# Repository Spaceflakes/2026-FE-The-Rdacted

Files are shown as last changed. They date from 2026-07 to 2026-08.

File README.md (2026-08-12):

# WRO-2026

# The Redacted


**The official repository of The Redacted for WRO - Future Engineers 2026**

## Content

### Folders
- **Engineering Manual:** Official manual of team The Redacted for WRO FE 26 (manual.pdf). Contains component selection, CAD, PCB schematics, and assembly guides.
- **PCBA:** Complete set of KiCad PCB files, manufacturing outputs (Gerbers), interactive HTML BOM, and documentation.
- **t-photos:** Team photos (1 formal, 2 informal).
- **v-photos:** 6 photos of the vehicle (front, back, left, right, top, bottom).
- **video:** video.md file with the official vehicle demonstration video link.
- **schemes:** Schematic diagrams, motor connections, power distribution, and 3D PCB renders.
- **src:** ROS 2 control software nodes (motion, LiDAR, camera/vision, parking logic).
- **models:** 3D CAD model files (STEP format).

### Index
- [The Redacted](#the-redacted)
- [Vehicle Photos and Video](#vehicle-photos-and-video)
- [Hardware Materials](#hardware-materials)
- [Mobility Management](#mobility-management)
- [Design](#design)
- [Power Management and Sense Management](#power-management-and-sense-management)
- [Schematic Diagram](#schematic-diagram)
- [Obstacle Management](#obstacle-management)
- [Our Journal](#our-journal)
- [Gantt Chart](#gantt-chart)

---

## The Redacted

### Members
1. **Anvay Jain**  
   Grade 9, The Sanskaar Valley School. Head of this repository. Interested in Space, Science, KSP, and Mathematics.
2. **Siddesh Jain**  
   12th Grader, Billabong High International School. Lead engineer/development head. CAD, hardware, system architecture.
3. **Prayash**  
   Co-engineer and robotics developer. Software integration, testing, and mechanical assembly.

### Team Pictures
#### Formal
Formal Team Photo

#### Informal
Informal Team Photo 1  
Informal Team Photo 2

---

# Vehicle Photos and Video

### Photos
Vehicle photographs showing all 6 sides are available in the [/v-photos](./v-photos) folder.

### Videos
The demonstration video link and operational breakdown are located in [/video/video.md](./video/video.md).

---

## Hardware Materials

| Name | Link |
| :--- | :--- |
| Rpi 4B/5 | [Link](https://www.raspberrypi.com/products/raspberry-pi-5) |
| LiDAR | [Link](https://robu.in/product/ydlidar-x4-pro-360-degree-ros-scanner-for-navigation-collision-avoidance-10m/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) |
| Servo | [Link](https://robu.in/product/surpass-hobby-25kg-s2500m-servo/) |
| Wheels | [Link](https://robu.in/product/65mm-robot-smart-car-12-rim-wheel-blue/) |
| Pi Camera | [Link](https://robu.in/product/arducam-8mp-imx219-175-degree-ultra-wide-angle-raspberry-pi-camera-module-compatible-with-raspberry-pi-4-model-b-pi-3-3b-and-pi-zero-2w/) |
| Custom 2026 WRO Hat PCB | [Link](https://github.com/The-Redacted/WRO-2026/tree/main/PCBA) |
| ESC + Motor | [Link](https://www.hobbywingdirect.com/collections/quicrun-brushless-system/products/quicrun-wp-10bl120-sl-system-g2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) |
| Battery | 2x DOGCOM 4S 850 mAh 150C LiPo |
| Gears | Custom 3D Printed Bevel Gears |
| PCB Components | TI LM61460 (5.15V @ 6A) & TPS62932 (8V @ 2A) |
| Carbon Fiber Stock | 12mm OD x 10mm ID Tubes & 3mm OD Rods |

### PCB Design & Prototype PCB
#### Prototype PCB
- **Issue:** Standard 5.0V buck converters caused under-voltage warnings on the Pi 4B under load.
- **Solution:** Designed 2026 WRO Hat for a stabilized 5.15V rail at 6A using the TI LM61460.
- **LC Hot-Plug Fix:** Added a 1000 µF electrolytic capacitor between switch output and GND to dissipate inrush energy and prevent voltage ringing.

#### PCB Design
- **4-Layer Stackup:**
    - Layer 1: High-speed switching/control.
    - Layer 2: Ground plane.
    - Layer 3: Power planes (BATT, 5.15V, 8.0V).
    - Layer 4: Ground plane and secondary signals.

---

## Mobility Management
- **Drive System:** Surpass Hobby 3674 1700KV brushless motor + 120A 4S ESC.
- **Differential Gearbox:** 3D-printed, 2:7 gear reduction ratio.
- **Steering:** Direct-drive Ackerman system with S2500M 25 kg-cm servo on 8V rail.
- **Bearing/Axle Support:** Needle roller/thrust bearings for front knuckles; carbon fiber tubes for rear axles.

---

## Design
- **Wheelbase:** 184.3 mm.
- **Width:** <180 mm.
- **Height:** <80 mm.
- **Chassis:** Carbon fiber rods for structural rigidity.

---

## Power Management and Sense Management

### Power Management
- **Battery:** 2x DOGCOM 4S 850 mAh LiPo in parallel (1700 mAh total).
- **5.15V Rail:** TI LM61460 (6A) for RPi 4B and LiDAR.
- **8.0V Rail:** TI TPS62932 (2A) for steering servo.

### Sense Management
- **YD-LiDAR X4 Pro:** 360° 2D Laser Range Finder for mapping/navigation.
- **Arducam IMX219:** 175° FOV camera for pillar color classification.

---

## Schematic Diagram
- **Power Input:** XT30 connector (14.8V–16.8V).
- **Interfaces:** RPi 4B GPIO, USB (LiDAR), CSI (Camera), Expansion Ports (ToF sensors).

---

## Obstacle Management

### Strategy
Uses ROS 2 for modularity, combining LiDAR for 3D mapping and Camera for 2D pillar color classification.

### Logic
- **Round 1 (Open):** Wall-following via LiDAR and lane maintenance.
- **Round 2 (Obstacle):** Pillar detection -> Camera classification -> Dynamic path planning.
- **Parking:** Automated sequence using LiDAR/Camera boundary detection and PID feedback.

---

## Our Journal
- **June:** Strategy, sensing evaluation, concept sketches.
- **July:** CAD modeling, PCB design, tire molding, printing.
- **August:** Assembly, PCB reflow, ROS 2 software development, documentation.

**The journal is one of the most detailed description and accounts for all the decision made. It should most definitely be read.**

---

## Gantt Chart

| Task / Milestone | June | July | August |
| :--- | :--- | :--- | :--- |
| Concept & Selection | X | | |
| 3D CAD Modeling | | X | |
| KiCad PCB Design | | X | |
| SLA Tire Molds | | X | |
| 3D Print & Assembly | | X | X |
| PCB & Reflow | | | X |
| ROS 2 Software | | | X |
| Integration & Testing | | | X |

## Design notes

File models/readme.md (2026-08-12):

# Models Directory (/models) - 3D CAD Files & Hardware Overview

**Team:** The Redacted  
**File Format:** 3D CAD STEP (`.step` / `.stp`)  
**License:** GNU Affero General Public License v3.0 (AGPLv3)

---

## Directory Structure & CAD File Index

This folder contains all 3D CAD models (STEP format), manufacturing jigs/molds, and hardware specifications for the vehicle assembly.

```text
models/
├── Acc/                     # Accessories & Mounting Hardware
│   ├── Raspberry Pi Mount.step  # Mounts RPi 4B to bottom 3mm carbon fiber spine rods (2x M2.5x8mm screws)
│   └── ESC Wire Mount.step      # Zip-tie routing guide for motor and ESC power leads
├── Center/                  # Central Chassis Frame & Sensor Mounts
│   ├── Top Brace.step           # Main structural chassis bridge connecting motor mount to steering column
│   ├── Bottom Left Brace.step   # Interlocking lower left brace connecting top brace to bottom carbon fiber spine
│   ├── Bottom Right Brace.step  # Interlocking lower right brace connecting top brace to bottom carbon fiber spine
│   ├── Left Bearing Mount.step  # Holds BCWG-NK12/12 needle roller bearing and left battery strap
│   ├── Right Bearing Mount.step # Holds BCWG-NK12/12 needle roller bearing and right battery strap
│   └── LiDAR & ESC Mount.step   # Platform mounting YD-LiDAR X4 Pro and Surpass 120A ESC
├── Diff/                    # Differential Gearbox Assembly (2:7 Net Reduction)
│   ├── Spider Gear.step         # 3x 9T Bevel Gears (m=1.5, 20° PA, 30.96° Bevel Angle)
│   ├── Main Gear.step           # 2x 15T Bevel Gears (m=1.5, 20° PA, 59.04° Bevel Angle)
│   ├── Spider Center.step       # Triangular carrier suspending spider gears (via 3x M3x10mm Button Head screws)
│   ├── Left Housing.step        # Left housing half with integrated 28T ring gear (houses 6901ZZ bearing)
│   ├── Right Housing.step       # Right housing half (houses 6901ZZ bearing)
│   ├── Attaching Cup.step       # Split mounting cups connecting main gears to 12mm carbon fiber rear axles
│   └── Spacer Disk.step         # PLA pre-load shim between housing and outer 6901ZZ bearings
├── Rear/                    # Rear Drivetrain & Axle Mounts
│   ├── Rear Axle Mount Front.step # Motor mount housing 3674 motor, bottom carbon rods, and M3 heat-set inserts
│   └── Rear Axle Mount Rear.step  # Rear back mount holding BCWG-NK12/12 & 6901ZZ bearings and top carbon rods
├── Screws BOM.csv           # Complete hardware Bill of Materials (screws, nuts, inserts, standoffs, bearings)
├── Steering/                # Direct-Drive Ackerman Steering Assembly
│   ├── Front Wheel Adapter Pin.step # 12mm OD capped pins with BCWN-T-d12-IR combined needle/thrust bearings
│   ├── Steering Knuckle.step    # Clamping knuckles holding thrust bearings (uses 2x M3x12mm screws & nuts per knuckle)
│   ├── Top Brace.step           # Upper steering column mount for S2500M servo and IMX219 camera
│   ├── Bottom Brace.step        # Lower steering column brace spanning wheelbase
│   ├── Side Brace.step          # Side column braces with M3 heat-set inserts
│   ├── Servo Horn.step          # Clamps to servo shaft with press-fit M3x6mm brass standoff spacer
│   ├── Servo Link.step          # Linkage arm connecting servo horn to steering rod
│   ├── Wheel Link.step          # Linkage arm connecting steering rod to steering knuckle (uses M2x20mm screw)
│   └── TPU Spacer.step          # 95A TPU shims (16mm OD x 12.8mm ID) providing pre-load on thrust bearings
├── Tools/                   # Manufacturing Jigs & Fabrication Molds
│   ├── Tire Mold.step           # 2-part SLA/FDM mold for polyurethane tires (clamps with 4x M3x30mm screws & nuts)
│   ├── Standoff Cutting Tool.step # Razor slot jig for trimming nylon standoffs to 14mm
│   ├── Axle Cutting Jig.step    # Saw guide for cutting 12mm carbon fiber tube axles to ~60mm
│   └── Axle Drilling Guide.step # Precision guide for drilling 2mm holes at 4.5mm offset on carbon fiber tubes
└── Wheel Hub.step           # 3D STEP model for custom wheel hub (18mm width, fuzzy skin tire interface)
```

## 3D Printing & Material Guidelines

* **Slicer Setup:** Orca Slicer / PreFlight using the Arachne wall engine.
* **Perimeters & Infill:** 3 perimeters (0.4 mm nominal nozzle), 25% Gyroid infill. Use 100% solid infill for steering links and TPU spacers.
* **Layer Heights:** 0.20 mm for structural chassis parts and mounts; 0.12 mm for gears, differential housing, and steering linkage parts.
* **Materials:**
  * **PLA:** Standard chassis structures, gears, housing, and mounts.
  * **TPU (95A Shore Hardness):** Front bearing stack pre-load shims (`Steering/TPU Spacer`).
  * **Resin (SLA):** Two-part polyurethane tire casting molds (`Tools/Tire Mold`).
* **Non-Printed Stock:** 12mm OD x 10mm ID roll-wrapped carbon fiber tubes (rear axles) and 3mm OD solid pultruded carbon fiber rods (spine and steering rods).

---

## Hardware Summary (Screws BOM.csv)

A complete component-by-component hardware listing is provided in `Screws BOM.csv` within this folder, including:

* **Screws:** M2x12mm, M2x20mm, M2.5x8mm, M3x8mm (Socket/CSK), M3x10mm (Socket/Button/CSK), M3x12mm, M3x16mm, M3x20mm (Socket/Button), M3x30mm.
* **Nuts & Inserts:** M2, M2.5, M3 Hex Nuts; M3x4mm and M3x6mm Brass Threaded Heat-Set Inserts.
* **Standoffs & Bearings:** M2.5x15mm Nylon Standoffs (cut to 14mm), M3x6mm Brass Standoffs, BCWN-T-d12-IR Thrust Bearings, 6901ZZ Ball Bearings, and BCWG-NK12/12 Needle Roller Bearings.

---

## License

All CAD files (`.STEP`) in this directory are released under the **GNU Affero General Public License v3.0 (AGPLv3)**. Any modified or derivative 3D models must be made publicly available under the same license terms.

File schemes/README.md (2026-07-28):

Electromechanical diagrams
====

`PCB V1.1 Schematic.pdf` is the PDF output of the schematic from KiCAD. It is the electrical schematic of the PCB used. Version 1.0 had an error (covered in `Engineering Manua/manual.pdf`. V1.1 is the fixed version.

The schematic is divided into 3 pages. The main page has the power connector and the power switch. The power page containst he circuitry for the buck converters. The logic page has the Raspberry Pi and the sensor connection.

The ROS2 node schematic will also be added here.

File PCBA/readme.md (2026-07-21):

# PCB Design Files

This directory contains the complete set of KiCad Printed Circuit Board (PCB) files, manufacturing outputs, and documentation required to view, modify, assemble, and produce this board.
---

## Directory Contents

Here is a quick overview of the essential files included in this folder:

| File / Folder Name | Type | Description |
| --- | --- | --- |
| **`interactive bom.html`** | HTML | Interactive Bill of Materials tool for easy manual assembly and component placement. |
| **`PCB BOM.csv`** | CSV | The complete, standard Bill of Materials listing all required electronic components, values, and footprints. |
| **`PCB_Schematic.pdf`** | PDF | A high-resolution PDF export of the circuit schematic for quick reference without needing CAD software. |
| **`KiCAD/production/WRO_Hat_V1.5.zip`** | ZIP Archive | The compiled Gerber and Drill files, ready to be uploaded to your favorite PCB manufacturer. |
| **KiCad Source Files** | KiCad | The raw `.kicad_pro`, `.kicad_sch`, and `.kicad_pcb` files for editing the design. |

---

## Detailed File Breakdown

### 1. The Interactive BOM (`interactive bom.html`)

This is a highly useful tool generated by the **InteractiveHtmlBom** plugin. If you plan on soldering this board yourself, simply open this file in any modern web browser. It provides a visual representation of the PCB, allowing you to highlight components, track your progress, and see exactly where each part belongs.

### 2. Standard Bill of Materials (`PCB BOM.csv`)

If you are ordering parts from suppliers like DigiKey, Mouser, or LCSC, this CSV file is your go-to resource. It contains a tabular breakdown of every resistor, capacitor, IC, and connector required.

### 3. Manufacturing Gerbers (`WRO_Hat_V1.5.zip`)

This ZIP archive contains all the industry-standard RS-274X Gerber files and Excellon drill files required by board houses (such as JLCPCB, PCBWay, or OSH Park).

* **Location:** Navigate to the `KiCAD/production/` folder to find this archive.
* **Usage:** Simply upload the `.zip` file directly to the manufacturer's quote page.

### 4. Schematic Reference (`PCB_Schematic.pdf`)

For software engineers writing firmware or hardware reviewers checking pinouts, the PDF schematic offers a clean, easily readable map of the entire circuit. It is fully searchable, making it easy to trace specific signals or power rails.

---

## Getting Started with KiCad

If you want to view or modify the raw board design:

1. Ensure you have the latest version of **KiCad EDA** installed on your system.
2. Clone or download this repository to your local machine.
3. Open the `.kicad_pro` project file in the main directory.
4. Launch the **Schematic Editor** or **PCB Editor** directly from the KiCad project manager.

---

> Important Note: Before sending the Gerber files for manufacturing, please verify that the design meets your specific board house's capabilities and tolerances (minimum trace width, hole size, and clearance).

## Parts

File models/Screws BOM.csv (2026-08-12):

Category | Component | Specification / Fastener Type | Head / Drive Type | Assembly Qty | Application / Where Needed
Screws | M2 x 12mm Screw | M2 x 12mm | Socket Head | 4 | Wheel Hubs to Axles (1x per wheel hub across 4 wheels)
Screws | M2 x 20mm Screw | M2 x 20mm | Socket Head | 6 | Steering Links to Knuckles (2x) and Front/Rear Axle Pins (4x)
Screws | M2.5 x 8mm Screw | M2.5 x 8mm | Socket Head (Black Oxide) | 6 | Raspberry Pi Mount to Pi (2x) and Pi to Nylon Standoffs (4x)
Screws | M3 x 8mm Screw | M3 x 8mm | Socket Head | 22 | Motor to Front Mount (6x) Rear Axle Back Mount (8x) Top Brace to Motor Mount (6x) Top Brace to Knuckles (2x)
Screws | M3 x 8mm CSK Screw | M3 x 8mm | Countersunk (CSK) | 2 | Bottom Brace to Steering Knuckles (2x)
Screws | M3 x 10mm Screw | M3 x 10mm | Socket Head | 2 | Servo Link to Steering Linkage Pins (2x)
Screws | M3 x 10mm Button Screw | M3 x 10mm | Button Head | 3 | Differential Gearbox Spider Center suspension (3x)
Screws | M3 x 10mm CSK Screw | M3 x 10mm | Countersunk (CSK) | 5 | LiDAR & ESC Mount to LiDAR (3x) and Bottom Brace to Side Braces (2x)
Screws | M3 x 12mm Screw | M3 x 12mm | Socket Head | 6 | Steering Knuckle Clamps (2 per clamp x 2 knuckles = 4x) and Top Brace to Steering Mount (2x)
Screws | M3 x 16mm Screw | M3 x 16mm | Socket Head | 2 | Optional frame structural reinforcement / general assembly
Screws | M3 x 20mm Screw | M3 x 20mm | Socket Head | 4 | Steering Servo to Top Brace (4x)
Screws | M3 x 20mm Button Screw | M3 x 20mm | Button Head | 4 | Differential Main Gears to Axle Attaching Cups (2 per gear x 2 gears = 4x)
Screws | M3 x 30mm Screw | M3 x 30mm | Socket Head | 7 | Differential Gearbox Housing halves (3x) and Tire Mold Tool clamping (4x)
Nuts | M2 Hex Nut | M2 | Hex (SS304) | 4 | Wheel Hub and Axle pin retention nuts
Nuts | M2.5 Hex Nut | M2.5 | Hex (SS304) | 4 | Raspberry Pi Mount and Standoff retention nuts
Nuts | M3 Hex Nut | M3 | Hex (SS304 / Mild Steel) | 11 | Steering Knuckle Clamps (4x) Differential Housing (3x) and Tire Mold Tool clamping (4x)
Standoffs | M2.5 Nylon Standoff | M2.5 x 15mm (cut to 14mm) | Female-Female Hex | 4 | Mounting spacing between Raspberry Pi 4B and Custom PCB Hat
Standoffs | M3 Brass Standoff | M3 x 6mm | Female-Female Hex | 1 | Press-fit spacer inside Servo Horn (1x)
Heat-Set Inserts | M3 x 4mm Heat-Set Insert | M3 x 4mm (3mm OD) | Slant Knurled Brass | 4 | Rear Axle Front Mount (Motor Mount) rear interface to Back Mount (4x)
Heat-Set Inserts | M3 x 6mm Heat-Set Insert | M3 x 6mm (3mm OD) | Slant Knurled Brass | 19 | Top Brace front (2x) Side Braces (6x) Rear Axle Front Mount sides (6x) Top Brace center (2x) LiDAR/ESC Mount (3x)
Bearings | Combined Needle/Thrust Bearing | BCWN-T-d12-IR (12mm ID) | Roller Thrust | 2 | Front Steering Knuckles (2x)
Bearings | Deep Groove Ball Bearing | 6901ZZ (12mm ID x 24mm OD x 6mm W) | Ball Bearing | 4 | Differential Gearbox Internal (2x) and External Housing Mounts (2x)
Bearings | Needle Roller Bearing | BCWG-NK12/12 (12mm ID x 19.5mm OD x 12mm D) | Needle Roller | 2 | Rear Axle Support Mounts (2x)
Carbon Fiber | 12mm Carbon Fiber Tube | 12mm OD x 10mm ID x 500mm | Roll Wrapped Twill | 1 | Rear Wheel Axles (2x cut to ~60mm)
Carbon Fiber | 3mm Carbon Fiber Rod | 3mm OD Solid x 1000mm | Pultruded Toe | 2 | Chassis Structural Spine (4x) and Steering Linkage Rods (2x cut to ~48mm)

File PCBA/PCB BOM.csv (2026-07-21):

Id | Designator | Footprint | Quantity | Designation | Supplier and ref
1 | C1, C2, C3, C4 | C_0603_1608Metric | 4 | 4.7u
2 | C5, C6, C7, C18 | C_0603_1608Metric | 4 | 47u
3 | C8, C9 | C_0603_1608Metric | 2 | 220n
4 | C10 | C_0603_1608Metric | 1 | 1u
5 | C11 | C_0603_1608Metric | 1 | 1p
6 | C12, C14, C16 | C_0603_1608Metric | 3 | 100n
7 | C13 | C_0603_1608Metric | 1 | 10u
8 | C15 | C_0603_1608Metric | 1 | 33n
9 | C17 | C_0603_1608Metric | 1 | 12p
10 | C19 | CP_Elec_8x10 | 1 | 220u
11 | C20 | CP_Elec_10x10 | 1 | 270u
12 | D1 | LED_D5.0mm | 1 | LED
13 | J1 | PinSocket_2x20_P2.54mm_Vertical | 1 | Raspberry_Pi_4
14 | J2 | AMASS_XT30PW-M_1x02_P2.50mm_Horizontal | 1 | XT30_Power
15 | J3 | PinHeader_1x05_P2.54mm_Vertical | 1 | TOF_Right
16 | J4 | PinHeader_1x05_P2.54mm_Vertical | 1 | TOF_Left
17 | L1 | L_Chilisin_BMRF00101040 | 1 | 6.8u
18 | L2 | L_Chilisin_BMRA00040415 | 1 | 15u
19 | M1 | PinHeader_1x03_P2.54mm_Horizontal | 1 | Throttle
20 | M2 | PinHeader_1x03_P2.54mm_Horizontal | 1 | Steering
21 | M3 | PinHeader_1x03_P2.54mm_Horizontal | 1 | Extra
22 | R1 | R_0603_1608Metric | 1 | 32.4k
23 | R2, R5 | R_0603_1608Metric | 2 | 100k
24 | R3 | R_0603_1608Metric | 1 | 1k
25 | R4 | R_0603_1608Metric | 1 | 24.3k
26 | R6 | R_0603_1608Metric | 1 | 90.9k
27 | R7 | R_0603_1608Metric | 1 | 10k
28 | SW1 | Switch | 1 | POWER
29 | SW2 | Switch | 1 | Program
30 | U1 | IC_LM61460AFSQRJRRQ1 | 1 | LM61460AFSQRJRRQ1
31 | U2 | SOT-583-8 | 1 | TPS62932

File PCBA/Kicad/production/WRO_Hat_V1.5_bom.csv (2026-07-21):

Designator | Footprint | Quantity | Value | LCSC Part #
C1, C2, C3, C4 | 0603 | 4 | 4.7u
C10 | 0603 | 1 | 1u
C11 | 0603 | 1 | 1p
C12, C14, C16 | 0603 | 3 | 100n
C13 | 0603 | 1 | 10u
C15 | 0603 | 1 | 33n
C17 | 0603 | 1 | 12p
C18 | 0805 | 1 | 47u
C19 | CP_Elec_8x10 | 1 | 220u | C341198
C20 | CP_Elec_10x10 | 1 | 270u | C251008
C5, C6, C7 | 0603 | 3 | 47u
C8, C9 | 0603 | 2 | 220n
D1, D2 | LED_D5.0mm | 2 | LED
J1 | PinSocket_2x20_P2.54mm_Vertical | 1 | Raspberry_Pi_4
J2 | AMASS_XT30PW-M_1x02_P2.50mm_Horizontal | 1 | XT30_Power
J3 | PinHeader_1x05_P2.54mm_Vertical | 1 | TOF_Right
J4 | PinHeader_1x05_P2.54mm_Vertical | 1 | TOF_Left
L1 | L_Chilisin_BMRF00101040 | 1 | 6.8u
L2 | L_Chilisin_BMRB00060618 | 1 | 15u
M1 | PinHeader_1x03_P2.54mm_Horizontal | 1 | Throttle
M2 | PinHeader_1x03_P2.54mm_Horizontal | 1 | Steering
M3 | PinHeader_1x03_P2.54mm_Horizontal | 1 | Extra
R1 | 0603 | 1 | 32.4k
R2, R5 | 0603 | 2 | 100k
R3 | 0603 | 1 | 1k
R4 | 0603 | 1 | 24.3k
R6 | 0603 | 1 | 90.9k
R7 | 0603 | 1 | 10k
SW1 | Switch | 1 | POWER
SW2 | Switch | 1 | Program
U1 | IC_LM61460AFSQRJRRQ1 | 1 | LM61460AFSQRJRRQ1 | C2871455
U2 | SOT-583-8 | 1 | TPS62932

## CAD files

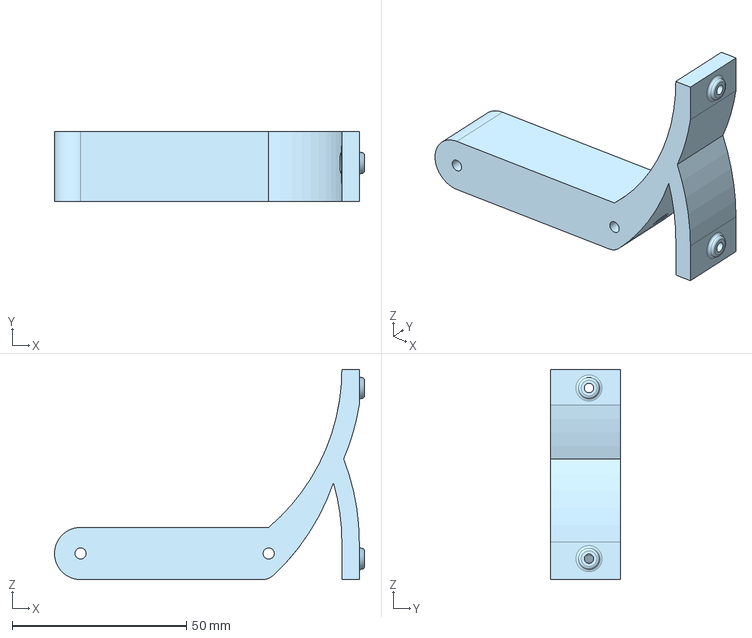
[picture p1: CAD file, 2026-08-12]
models/Acc/PI mount.step
89.0 x 20.0 x 60.4 mm

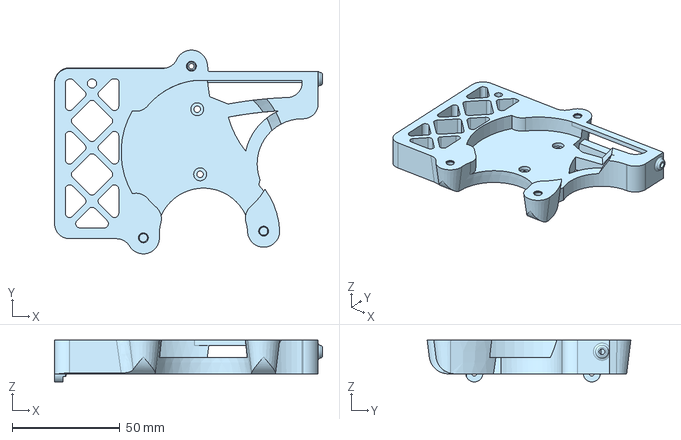
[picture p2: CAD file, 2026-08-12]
models/Center/Lidar Mount.step
124.3 x 94.5 x 19.4 mm

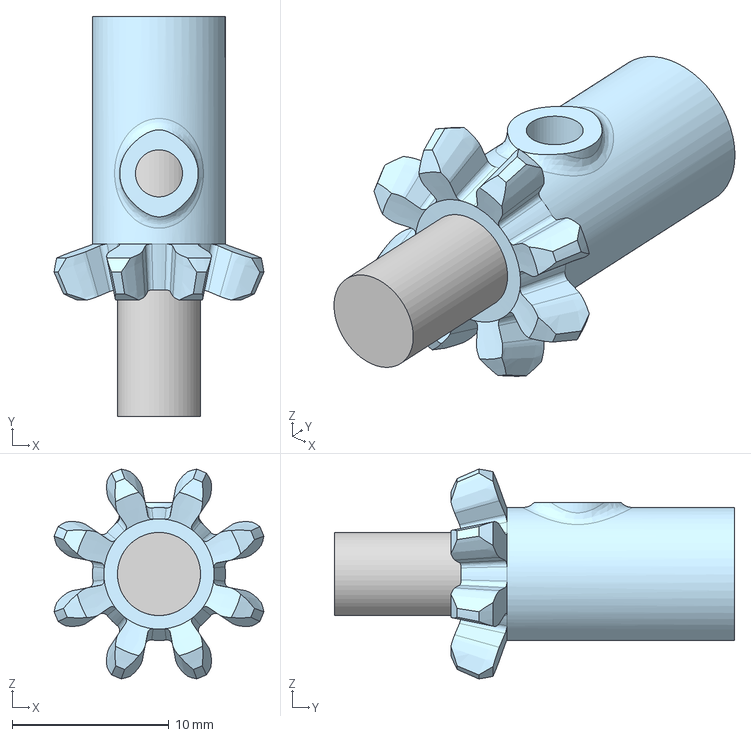
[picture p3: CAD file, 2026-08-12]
models/Diff/Motor Gear.step
13.4 x 25.5 x 13.4 mm

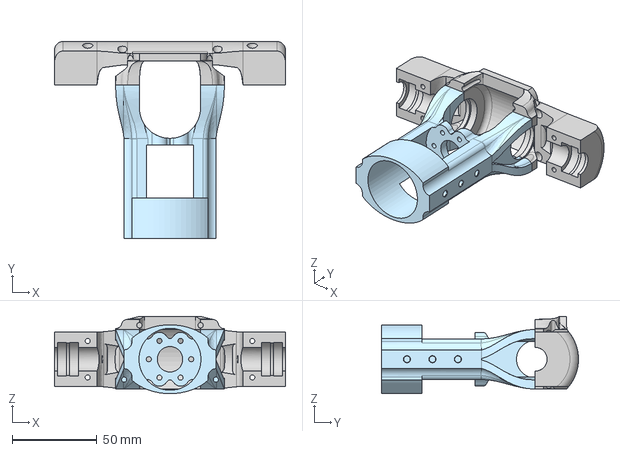
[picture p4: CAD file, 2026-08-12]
models/Rear/Rear Gearbox Mount.step
136.0 x 116.0 x 45.5 mm

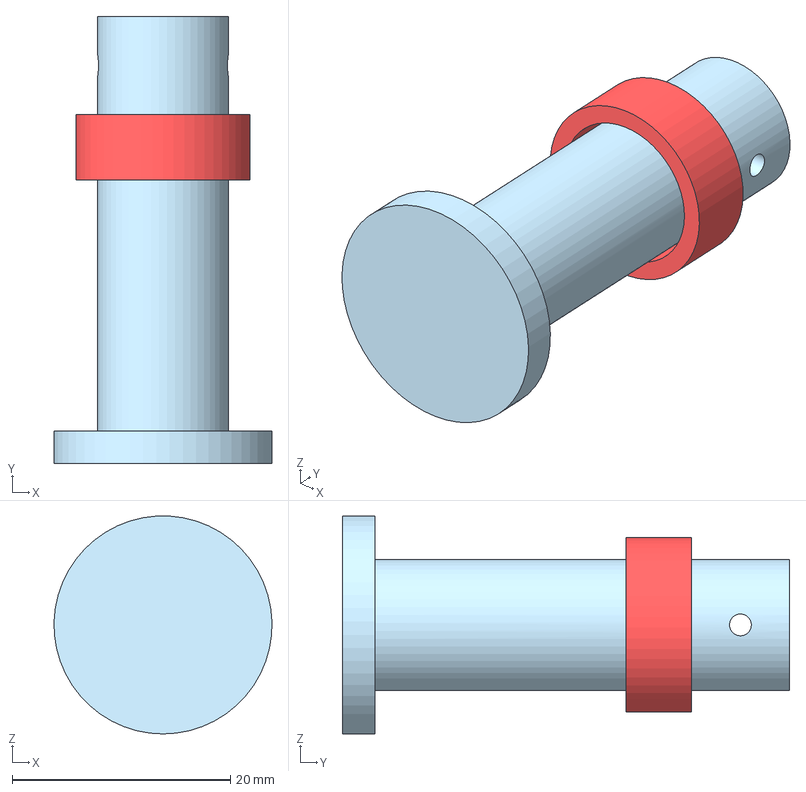
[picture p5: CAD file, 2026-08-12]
models/Steering/Front Wheel adapter.step
20.0 x 41.0 x 20.0 mm

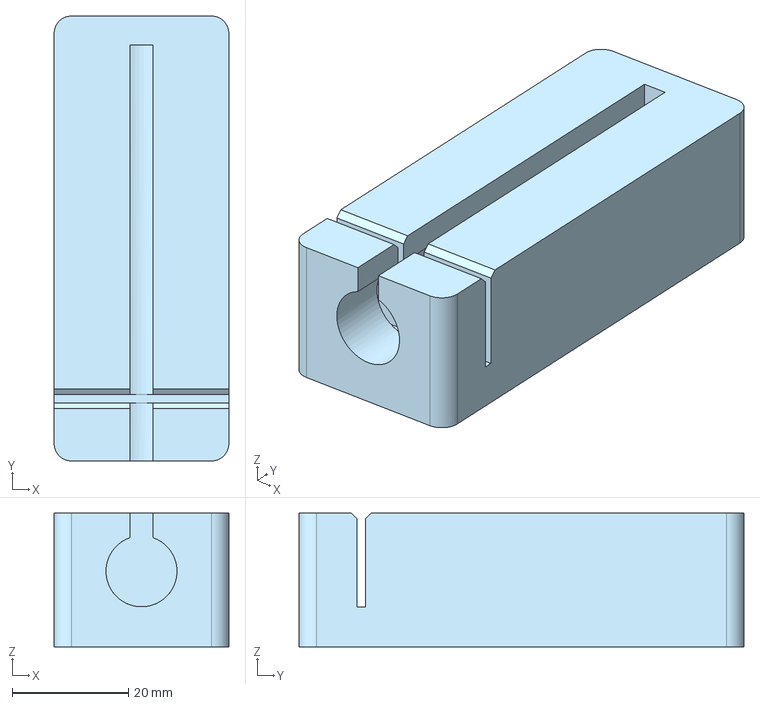
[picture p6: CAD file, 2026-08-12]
models/Tools/Rod Cutting Tool.step
30.0 x 76.4 x 23.0 mm

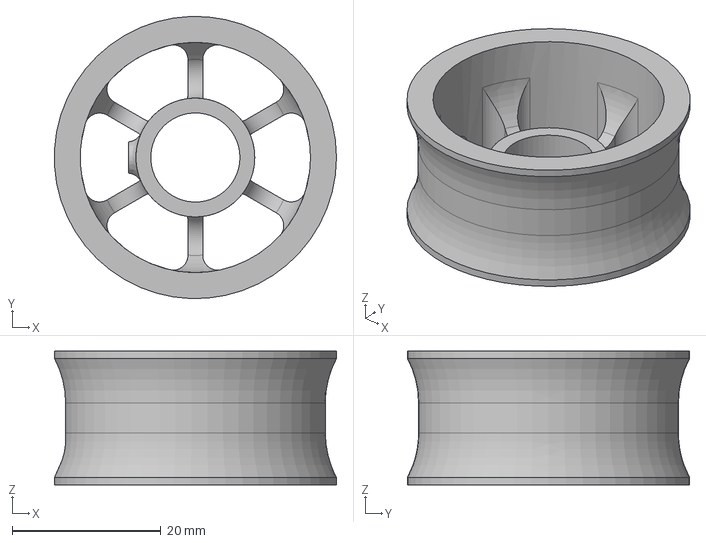
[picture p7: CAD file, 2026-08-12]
models/Wheel Hub.step
38.0 x 38.0 x 18.0 mm

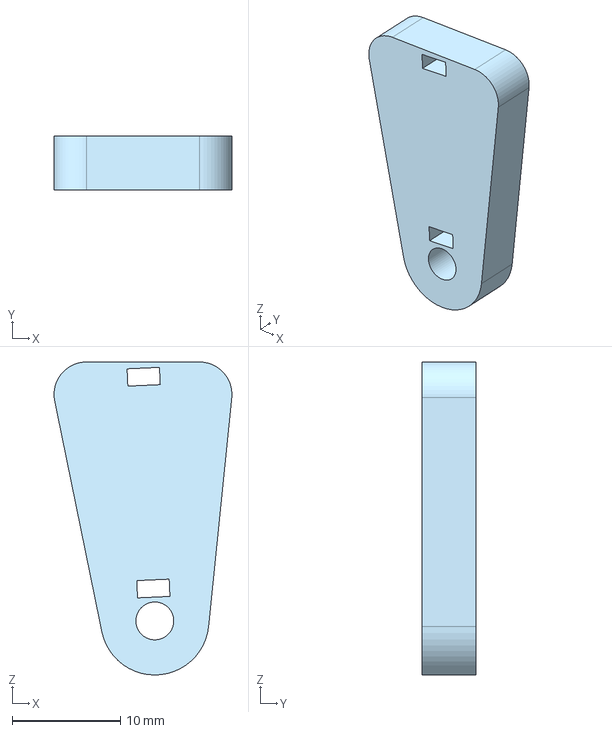
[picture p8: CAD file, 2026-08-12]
models/Acc/ESC Wire mount.step
16.4 x 5.00 x 28.9 mm

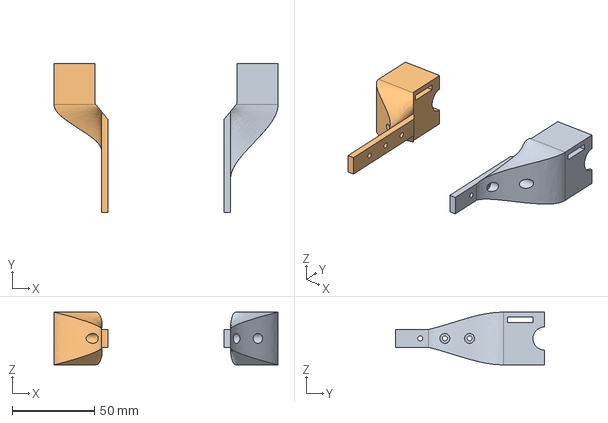
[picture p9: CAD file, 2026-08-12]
models/Center/Rear Bearing Mount.step
136.0 x 90.5 x 32.0 mm

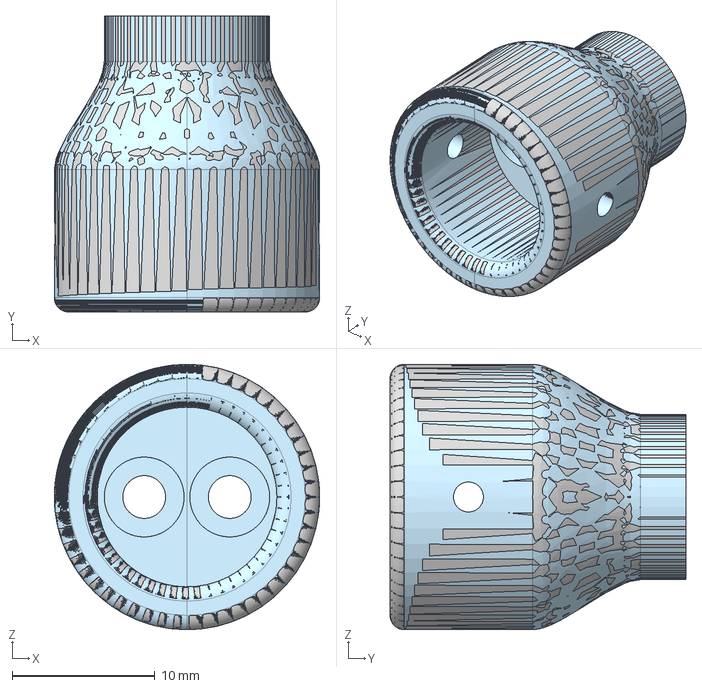
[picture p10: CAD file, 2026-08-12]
models/Diff/Cups.step
18.6 x 20.8 x 18.6 mm

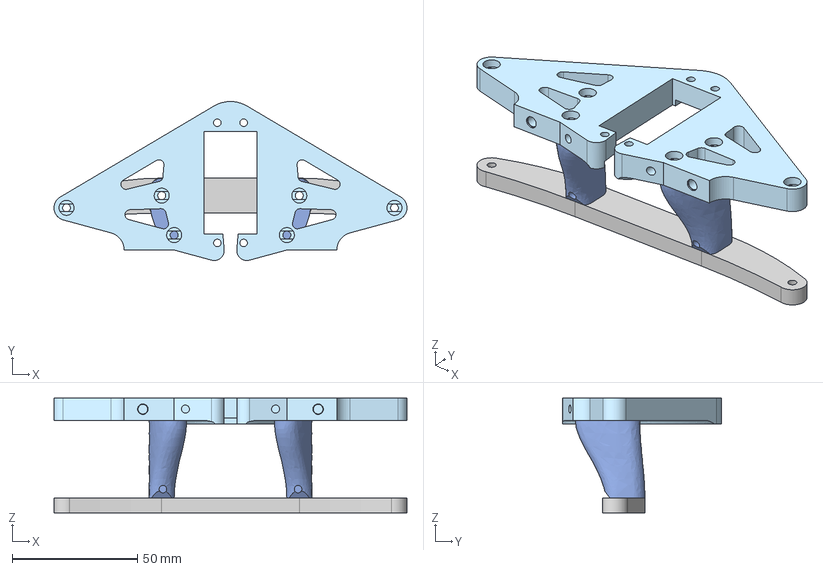
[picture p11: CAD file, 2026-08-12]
models/Steering/Steering COl.step
141.0 x 63.5 x 45.9 mm

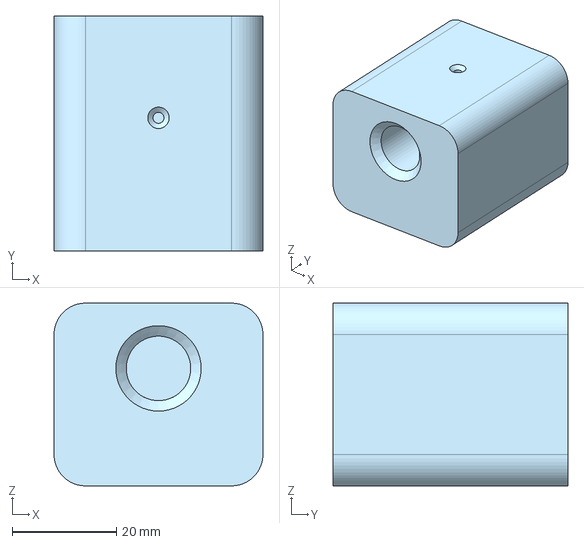
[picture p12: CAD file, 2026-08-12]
models/Tools/Rod Drilling Tool.step
40.0 x 45.0 x 35.0 mm

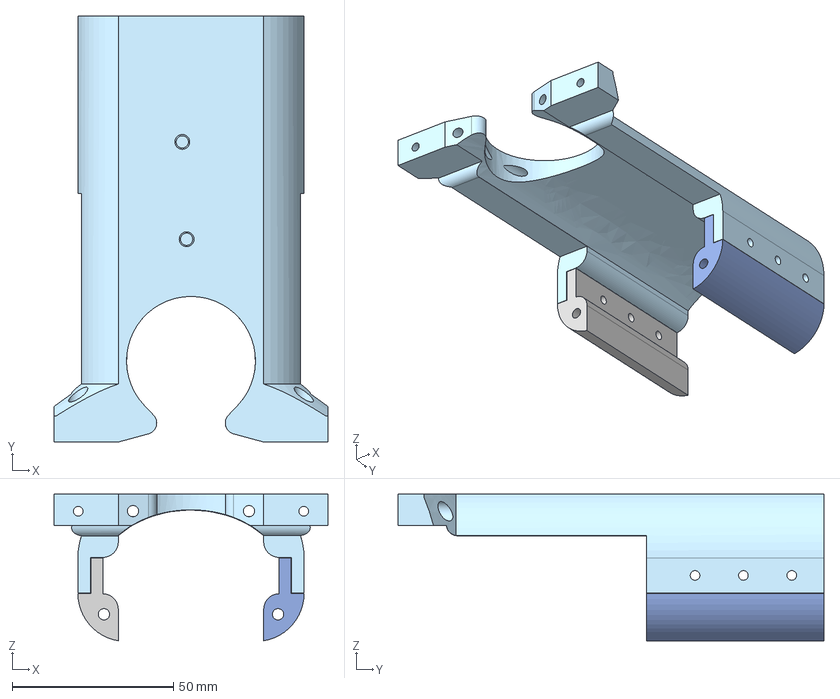
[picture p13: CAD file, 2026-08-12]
models/Center/Body Brace.step
85.0 x 132.2 x 45.5 mm

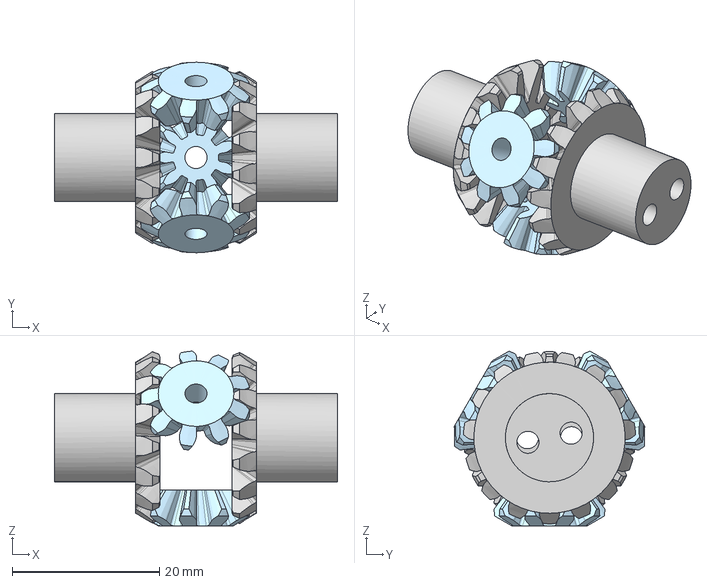
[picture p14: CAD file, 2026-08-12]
models/Diff/Diff Gears.step
38.5 x 25.9 x 23.8 mm

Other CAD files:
models/Steering/Steering Knuckle.step
models/Tools/Tire Mold.step
models/Diff/Spacer.step
models/Steering/Serov Horn.step
models/Diff/HOUSING.step
models/Steering/Steering Links.step
models/Tools/Standoff Cutting Tool.step

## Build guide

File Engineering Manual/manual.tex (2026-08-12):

\documentclass[12pt,a4paper]{article}
\usepackage[utf8]{inputenc}
\usepackage{amsmath}
\usepackage{amsfonts}
\usepackage{amssymb}
\usepackage{makeidx}
\usepackage{graphicx}
\usepackage{float}
\usepackage{subcaption}
\usepackage{hyperref}
\usepackage{wasysym}
\usepackage{booktabs}
\usepackage{tabularx}
\usepackage{tikz}
\usetikzlibrary{positioning, shapes.geometric, arrows.meta, calc}
\usepackage{enumitem}
\usepackage[left=2cm,right=2cm,top=3cm,bottom=2cm]{geometry}
\title{WRO Engineering Manual}
\author{Team: The Redacted}
\begin{document}

\begin{titlepage}
    \sffamily 
    \raggedright % Flushes all text to the left
    
    % --- LOGO ---
    \begin{center}
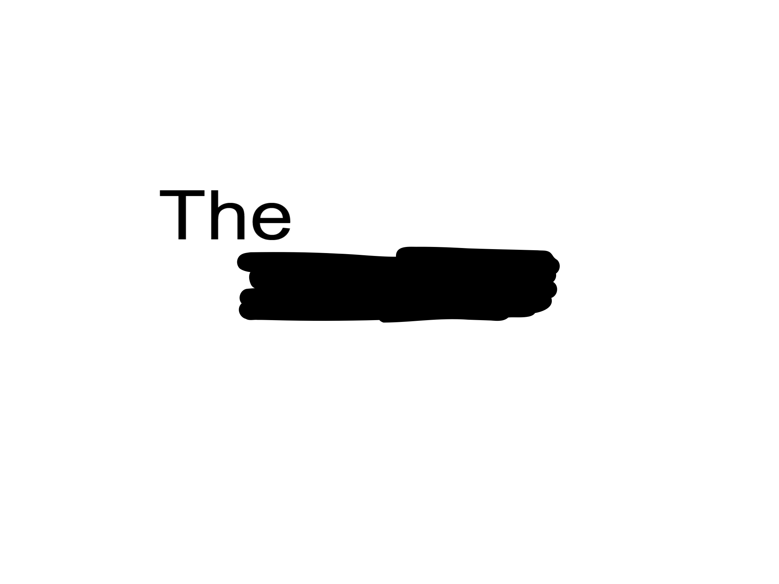
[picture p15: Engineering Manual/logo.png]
    	
	\end{center} 
	\vspace{3.5cm}
    
    % --- TITLE SECTION ---
    {\fontsize{42}{48}\selectfont \textbf{Engineering Manual}}\\[0.2cm]
    {\fontsize{30}{36}\selectfont WRO}\\[2cm] 
    
    \vfill 
    
    % --- AUTHOR SECTION ---
    {\Large \textbf{Team The Redacted}}\\[0.3cm]
    {\large \textcolor{darkgray}{\today}} % Gray date for subtle contrast
    \vspace*{1cm}
\end{titlepage}

\pagebreak

\tableofcontents

\pagebreak

\listoffigures

\pagebreak

\section{Selection of Components}

\subsection{Sensing}

The WRO Future Engineers challenge sets certain criteria on the needed hardware. The second challenge makes teams not just detect walls but the pillars and their colors, as well as the ability to parallel park. \\

This means that a comprehensive and accurate inference of the playing field is required. There are multiple paths one can go down to fulfill this, there are perhaps only two practical routes. One is using distance sensors along with a camera and the other is using a 2-dimensional LiDAR.  \\

The trade-offs between the two are fairly significant. The LiDAR comes at a higher cost than the camera and provides absolute and accurate cloud point data that can be used to detect the pillars and construct a map of the playing field with high accuracy. While the camera system is cheaper in the hardware cost, it has a significant cost in terms of compute. The detection of the actual pillars in the second round is easy, disregarding how slowly it would have to run and train (about $1/2-1$ Hz for good reliability on a wide FOV camera running YOLO, taking about 3 hours to train on 300 images, and a variable time to compute, not real time), lacks in the accuracy of positioning the pillars in dynamic environments. The LiDAR also provides very accurate and fast ($8-20$Hz) feedback for absolute positioning on the go, something the camera does not. The aspect of parallel parking also plays into the advantage of the LiDAR. The LiDAR can provide a lot more detail than a distance assisted vision system could provide. If one did not use a LiDAR, atleast 4 mutually perpendicular distance sensor, Time of Flight or Ultrasonic, would have to be implemented on an I2C bus. \\

All this made the case for using the LiDAR stronger. On smaller scales, where the camera is quite a bit lager than the vehicle and so is the LiDAR, using a LiDAR makes sense due to the current lack of compute density for very small and light boards being an issue. But, for larger vehicles, where the cost of cameras scales linearly and the LiDAR scales exponentially, using multiple cameras and cheaper, larger compute makes sense. Hence, we decided to use a LiDAR for our vehicle. \\

However, this did come at a major trade-off and design cost. We had to keep the whole vehicle shorter than 80 mm to accommodate for a clear view of the laser at about 90 mm and have a clearance of 10 mm from the top of the 100 mm arena walls to account for deviations in the walls and potentially the playing field as well. \\

For the actual hardware, the \textbf{YD-LiDAR X4 Pro} was chosen due to it's compatibility with ROS and it's relatively low cost and high scanning speed along with it's resolution. The X4 Pro provides the high range that is needed, extending from 8 centimeters to 10 meters. When measuring less than 8 centimeters, parallel parking for example, the fall further away will be utilized to interpolate. The USB interface of the LiDAR also was very handy along with the openly available library and drivers.

\begin{figure}[H]
    \centering
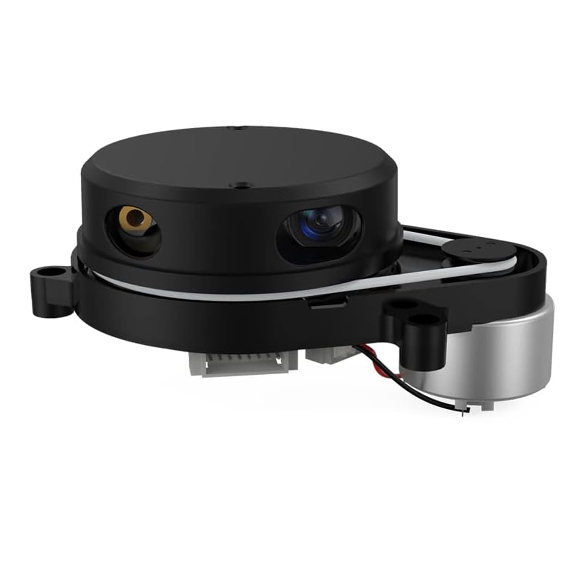
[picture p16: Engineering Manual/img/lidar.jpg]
    
    \caption{The YD-LiDAR X4 Pro.}
    \label{fig:X4_PRO} 
\end{figure}

Because the LiDAR only outputs the point cloud data, and we need to find the color of the pillars as well, a wide FOV camera is used in tandem. It is only used to determine the color of the pillar and not used for detection. The LiDAR detects the pillar and the image from the camera is then used to assign the color. This keeps the compute costs very low and allows for very fast inference. The camera used is the \textbf{Arducam IMX219 Wide Angle Camera}. It has a field of view of $175^\circ$. This allows us to have the maximum window for inference possible as we don't need the data resolution a camera based solution would.

\begin{figure}[H]
    \centering
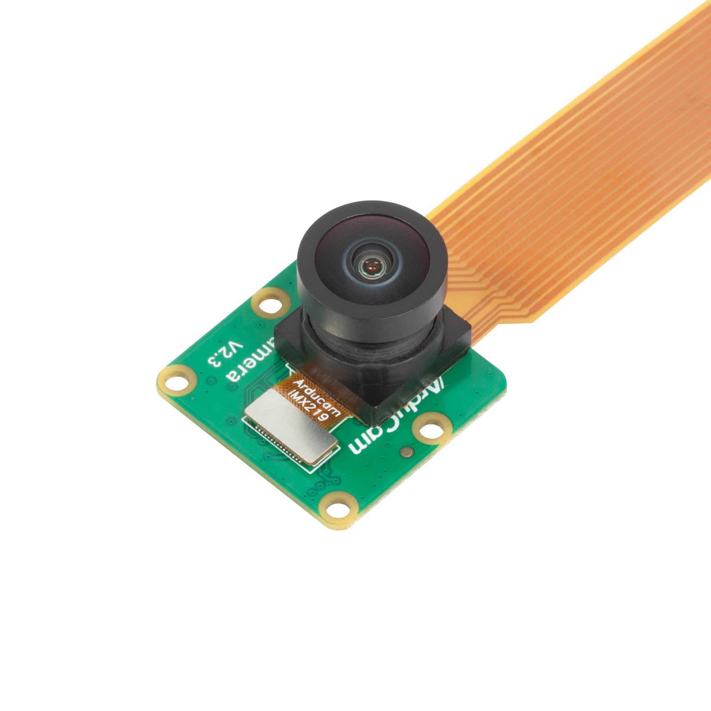
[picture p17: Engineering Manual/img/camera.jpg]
    
    \caption{The IMX219 with a very wide angle lens.}
    \label{fig:Cam} 
\end{figure}

\subsection{Compute}

The compute module doesn't need to be something excessive like the Jetson Orion Nano. The compute required to complete both the challenges is fairly low and could be done on an STM32 H7 micro-controller as well. The compute module has to fulfill the following requirements:

\begin{enumerate}
\item Small form factor.
\item Have a USB poet.
\item Have a Camera Serial Interface .
\item Run ROS or Micro ROS.
\item Have a decent number of exposed IO pins for accessories.
\item Have the ability to read/write code for easy iterations.
\end{enumerate}

This led to the Raspberry Pi 4B. Any other similar Single Board Computer (SBC) can be used. The 4GB RAM version was chosen so that a graphical user interface could be ran on it if needed when editing code during the competition. It would also provide sufficient headroom. A 2GB RAM version would have also been sufficient. A Raspberry Pi 5 would be overkill. The Pi 4 is also cheaper and easier to source. It would also have the compute needed to run the control loop at higher frequencies and have faster and more accurate control. \\

The only downside of the Rspberry Pi was it's size. It's a lot larger than needed, and occupies crucial space in the limited volume. This was solved with intentional and clever design. It's availability of USB ports and the CSI makes it a very appealing solution. Custom hardware, ST based micro-controller or a board with the Raspberry Pi Compute Module, can be used but would be harder to source and would involve a longer development time. The Raspberry Pi also acts as a drop in solution as it has an external micro-SD card where all the code is stored, allowing for easy access and replaceability.

\begin{figure}[H]
    \centering
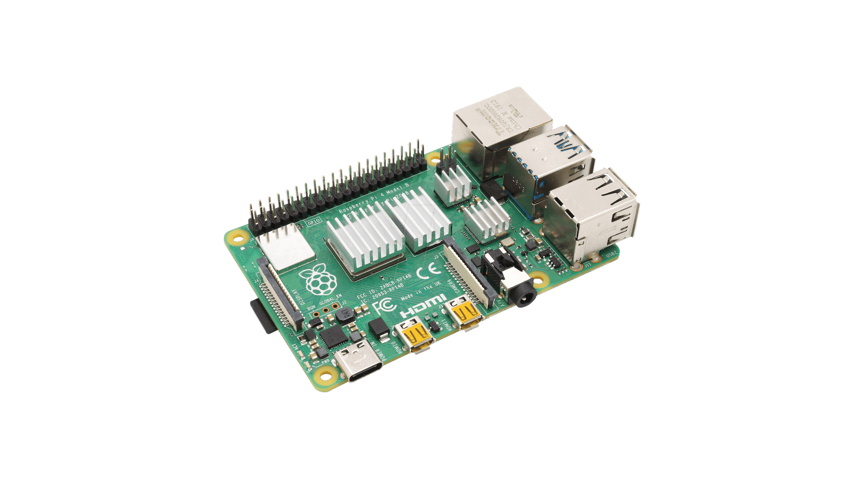
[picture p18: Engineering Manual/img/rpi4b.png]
    
    \caption{The Raspberry Pi 4 Model B.}
    \label{fig:Rpi} 
\end{figure}

\subsection{Motion}

A \textbf{rear wheel drive system} was chosen as it would distribute the complexity of the steering and drive systems, allowing easier manufacturing and assembly. The trade-off made here was that a \textbf{differential would be required} to prevent under steer that would be cause when turning at tight radii and slow speeds. This increases the complexity slightly, but not as much as using a drive and steering would need. \\

The motion system can be broken down into two parts, the drive system and the steering system. \\

\subsubsection{Drive System}

A brush less DC (BLDC) motor is proffered over a brushed motor due to it's higher resolution of speed changes particularly at a low speeds. That comes particularly handy when parallel parking. It is also preferred due to its efficiency and torque. The ideal case would be a stepper or BLDC motor with Field Oriented Control (FOC) as it would provide excellent position and torque control, but sourcing such FOC motor drivers in a small and compact size is very hard and expensive. A note should be made that developing such a custom FOC motor driver for 10-20A should not be hard but would take time. \\

For the motor, a Surpass Hobby \textbf{36 mm diameter in runner BLDC motor} is used. The 36 mm diameter is chosen as it provides enough \textbf{torque, acceleration and internal breaking} for a 1.5 kg vehicle. The length of the motor is 74 mm. This makes it a \textbf{3674 motor}. The motor is also widely used in scale RC cars and hence is easy to source. The motor is rated at \textbf{1700 kv}, which provides generous speed and high torque. \\

\begin{figure}[H]
    \centering
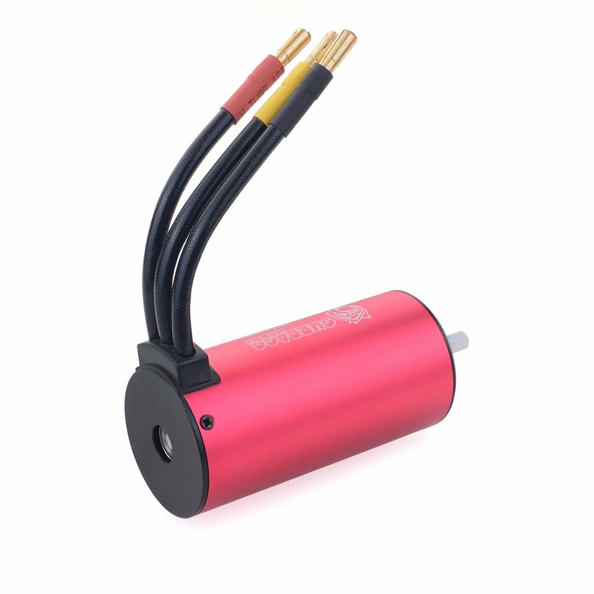
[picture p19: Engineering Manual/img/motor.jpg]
    
    \caption{The Motor.}
    \label{fig:motor} 
\end{figure}

A Surpass Hobby 3 Phase \textbf{120A 4S ESC} is used. This Electronic Speed Controller is preferred due to its high \textbf{reliability and headroom, along with its configurability}. The ESC can be configured to operate at certain speed, torque and braking levels with a configurator device. \\

\begin{figure}[H]
    \centering
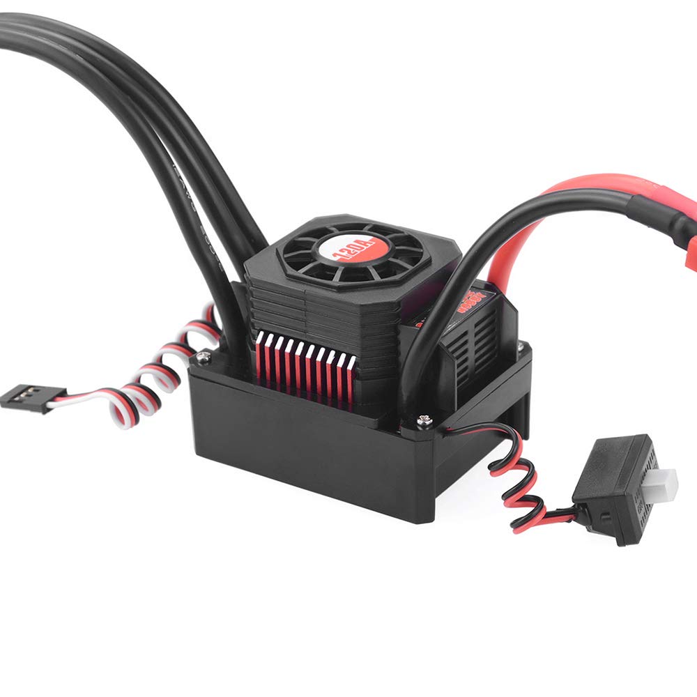
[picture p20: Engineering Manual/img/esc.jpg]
    
    \caption{The ESC.}
    \label{fig:ESC} 
\end{figure}

Do note that if built again, a shorter motor and lower ampere rated ESC would be used, something like a 3650 motor and a 60A ESC. The 3674 motor is too long and has excessive torque that is not really needed. The shorter motor should be used to reduce the weight as much as possible. The ideal motor would be a 3650 motor rated somewhere about 1000 kv. The 60A ESC would also be chosen to reduce weight. The current setup was chosen because it is what was available without purchasing new components. \\

\begin{figure}[H]
    \centering
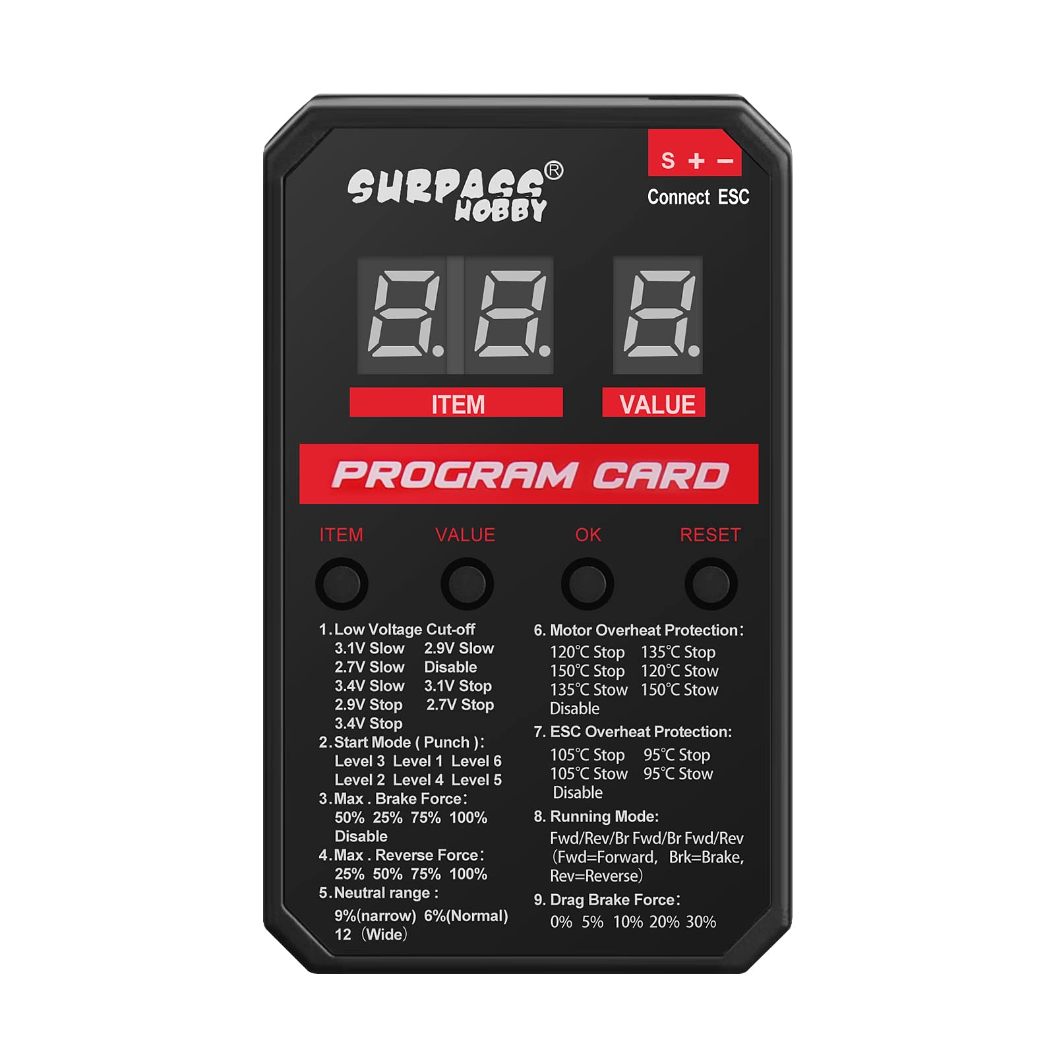
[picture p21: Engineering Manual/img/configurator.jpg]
    
    \caption{The Configuration Device that connects via PWM.}
    \label{fig:configurator} 
\end{figure}

\subsubsection{Steering System}

A \textbf{direct drive steering system} was chosen for the vehicle, meaning that the servo directly drives the wheels. This was chosen as the steering links would be manufactured using 3D printing and each joint would cause additional backlash in the linkage mechanism. A system with a grater mechanical leverage would hence be more complex and less accurate, while taking more volume. \\

The \textbf{S2500M} servo motor is used, which provides a torque of about 25 $\frac{kg}{cm}$ at about $8$V. This would be provide ample headroom in a direct drive steering system. The only downside to contend with in this system is its weight and the fact that the servo runs on $8$V, meaning it will need its own power supply. Do note that a lower torque servo that operates on $5$V can be used if needed, the S2500M was available without purchasing new components. \\

\begin{figure}[H]
    \centering
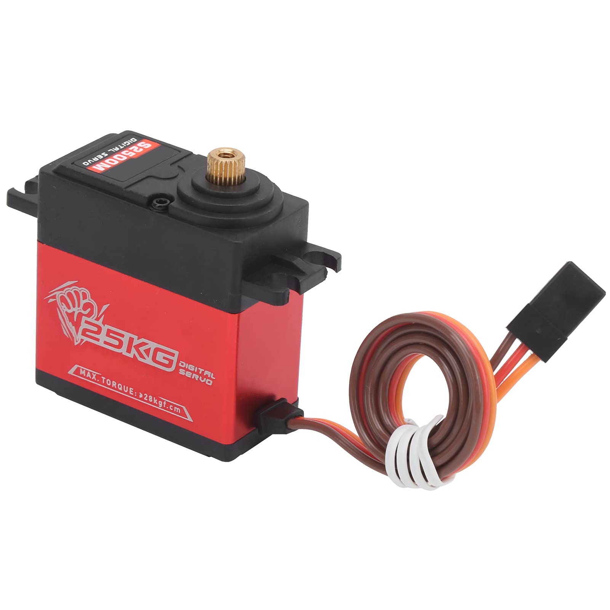
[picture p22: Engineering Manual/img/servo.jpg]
    
    \caption{The S2500M metal gear servo motor.}
    \label{fig:servo} 
\end{figure}

\subsection{Power Management}

The batteries were chosen on strict power consumption metrics. \\

\begin{table}[htbp]
\centering
\small
\caption{System Power Usage and Electrical Specifications}
\label{tab:power_usage}
\begin{tabularx}{\textwidth}{>{\raggedright\arraybackslash}X >{\raggedright\arraybackslash}p{2.2cm} >{\raggedright\arraybackslash}p{1.8cm} >{\raggedright\arraybackslash}p{2.2cm} >{\raggedright\arraybackslash}p{2.2cm} >{\raggedright\arraybackslash}X}
\toprule
\textbf{Component} & \textbf{Voltage Rail} & \textbf{Idle Current} & \textbf{Typical Draw} & \textbf{Peak Draw} & \textbf{Power Regulator / Impact} \\
\midrule
Raspberry Pi 4B (4GB) & 5.15V DC & 600 mA (3.1 W) & 1.2A--1.5A (6.2--7.7 W) & 2.2A--2.5A (11.3--12.9 W) & TI LM61460 (5.15V Buck); Primary SBC running ROS, vision, and control loops. \\
YD-LiDAR X4 Pro & 5.0V / 5.15V DC & 280 mA (1.4 W) & 330--380 mA (1.7--1.95 W) & 800--1000 mA (4.0--5.0 W) & 5.15V Rail; 360$^\circ$ 2D LiDAR for mapping, wall-following, and parking. \\
Arducam IMX219 & 3.3V / 5.0V DC & 100 mA (0.5 W) & 150--200 mA (0.75--1.0 W) & 300 mA (1.5 W) & RPi CSI Bus; 175$^\circ$ Ultra-Wide FOV camera for pillar color classification. \\
Surpass Hobby 3674 Motor & 14.8V--16.8V DC & 2.6A--3.1A (38.5--46 W) & 4.0A--7.0A (60--105 W) & 15A--25A (220--370 W) & Direct 4S LiPo; 1700KV BLDC rear drivetrain propulsion motor. \\
Surpass Hobby 120A ESC & 14.8V--16.8V DC & 100 mA (1.5 W) & 100--200 mA (1.5--3.0 W) & 120A Cont. / 760A Burst & Direct 4S LiPo; 3-Phase electronic speed controller with PWM interface. \\
S2500M Servo Motor & 8.0V DC & 100 mA (0.8 W) & 500mA--1.0A (4.0--8.0 W) & 1.8A--2.0A (14.4--16.0 W) & TI TPS62932 (8V Buck); 25 kg$\cdot$cm high-voltage metal gear steering servo. \\
Peripherals \& PCB Logic & 5.15V / 8.0V DC & 20 mA (0.1 W) & 50--100 mA (0.25--0.5 W) & 150 mA (0.75 W) & PCB Hat; Onboard status LEDs, switches, and ToF headers. \\
\midrule
\textbf{Total 5.15V Rail} & \textbf{5.15V DC} & \textbf{~1.0 A (5.15 W)} & \textbf{~1.8A--2.1A (9.3--10.8 W)} & \textbf{~3.5A--3.8A (18.0--19.6 W)} & Regulated by TI LM61460 (6A Cont. Limit). \\
\textbf{Total 8.0V Rail} & \textbf{8.0V DC} & \textbf{~0.1 A (0.8 W)} & \textbf{~0.5A--1.0A (4.0--8.0 W)} & \textbf{~1.8A--2.0A (14.4--16.0 W)} & Regulated by TI TPS62932 (2A Cont. Limit). \\
\textbf{Total System Draw} & \textbf{14.8V Nominal} & \textbf{~0.8 A (12 W)} & \textbf{~5.5A--8.5A (80--125 W)} & \textbf{~18A--28A (260--410 W)} & \textbf{2x DOGCOM 4S 850 mAh} (1700 mAh Total). \\
\bottomrule
\end{tabularx}
\end{table}

To provide adequate headroom for the 3+ minutes of operation needed, \textbf{2 DOGCOM 4S 850 mAh batteries were used in parallel}. A single 4S 850 mAh battery in testing at full motion capabilities provided power for about 2.5 minutes before it went below the safe discharge voltage of 3.5 V per cell. Hence a second battery is needed for headroom. \\

The 4S batteries are used as they have the maximum voltage compatible with the setup, allowing the maximum acceleration and torque for the vehicle. The batteries use a \textbf{Li-Po (Lithium Polymer)} chemistry as that provides the high discharge current needed. It is also widely available and hence easy to source. On a larger scale vehicle, Li-Ion cells would be used due to their longer discharge cycle rating as the only major draw back with Li-Po batteries are their lower charge cycle rating. \\

\begin{figure}[H]
    \centering
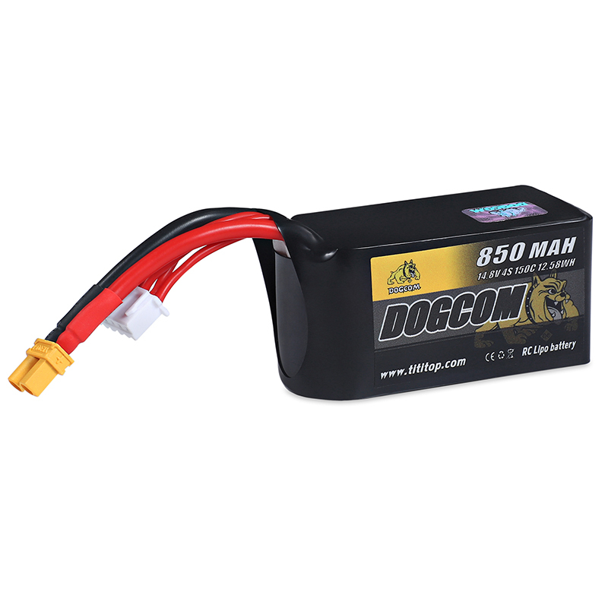
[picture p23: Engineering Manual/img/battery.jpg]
    
    \caption{The DOGCOM 4s 850 mAh battery.}
    \label{fig:battery} 
\end{figure}

\subsection{The Additional Hardware}

Additional hardware such as bearings and wheels are needed to build the vehicle. These are things that cannot be 3D printed and are manufactured in other ways or are sourced. \\

\subsubsection{Bearings}

For the two front steering knuckles, a \textbf{thrust roller bearing} is used. This is a type of bearing that combines a needle and thrust bearing in a single housing. It is used to constraint the location of the two front steering wheels though the axis of rotation and ensure there is no play present. If a normal roller ball bearing would be used, the outward and asymmetric torque of the wheel "pin" would misalign the groove and the balls causing excessive play. The thrust roller bearing is a compact solution used in real cars as well. \\

The inner diameter of the bearing is 12 mm. It is the "\textbf{BCWN-T-d12-IR}" bearing, sourced from JLCMC. \\

\begin{figure}[H]
    \centering
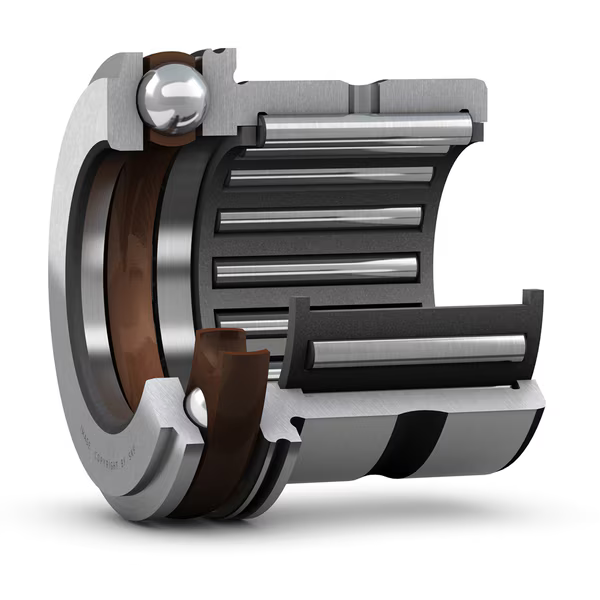
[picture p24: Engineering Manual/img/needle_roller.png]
    
    \caption{The internals of a Combined needle roller / thrust ball bearing.}
    \label{fig:needle_roller_thrust_bearing} 
\end{figure}

For the differential, traditional roller ball bearings were used as the axial forces transferred are not that high. The \textbf{6901ZZ} ball bearing is used as it is in a very compact package that has an internal diameter of 12 mm, an external diameter of 24 mm and a width of 6 mm, making it ideal to put in the already compact differential gear box. \\

\begin{figure}[H]
    \centering
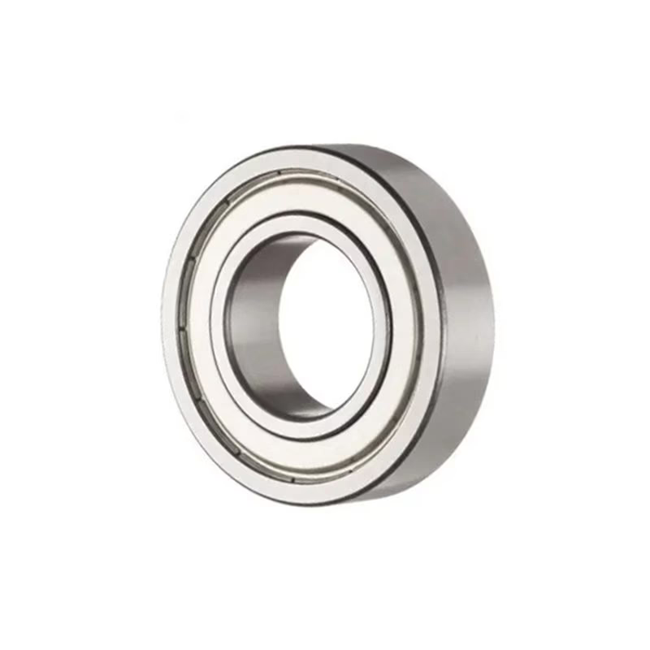
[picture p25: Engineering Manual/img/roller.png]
    
    \caption{The 6901ZZ roller ball bearing.}
    \label{fig:roller_bearing} 
\end{figure}
 
To support the rear axle, needle roller bearings are used. They are used as they have low friction and can withstand very high forces perpendicular to the axis of rotation, prefect for transferring the weight from the main body of the vehicle to the wheels. The "\textbf{BCWG-NK12/12}" bearing was used, sourced from JLCMC. It has an inner diameter of 12 mm, an outer diameter of 19.5 mm and is 12 mm deep. \\

\begin{figure}[H]
    \centering
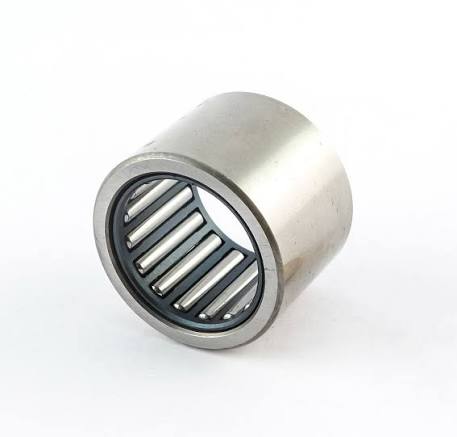
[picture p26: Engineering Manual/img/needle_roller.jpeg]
    
    \caption{The Needle Roller bearing.}
    \label{fig:needle_roller_bearing} 
\end{figure}

\subsubsection{Carbon Fiber Tubes}

Carbon fiber tubes were used at several places as axles, linkage connectors and structural connectors. This decision was made as carbon fiber has a very high tensile strength and is particularly very stiff perpendicular to it's length. \\

A combination of 2 diameters were used. The axle for the rear two wheels were made using \textbf{12 mm outer diameter} and 10 mm inner diameter carbon fiber tubes. Any aluminum or steel shaft could be used here, but a 3D printed shaft cannot be used as the layer lines of the print would be perpendicular to the layer lines, leading to very weak prints. Carbon fiber was used as it is light weight and relatively easy to source in \textbf{roll wrapped rods}. This tube consists of "twill" and not "toe". \\

\begin{figure}[H]
    \centering
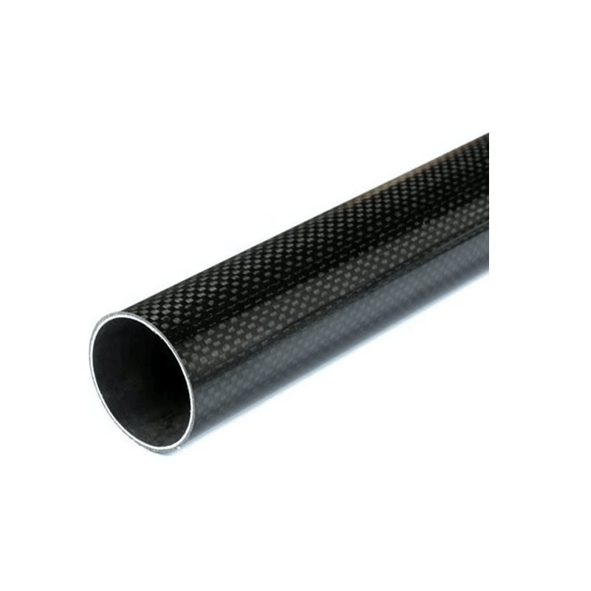
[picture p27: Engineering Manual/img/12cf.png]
    
    \caption{The 12 mm CF rod.}
    \label{fig:12mm_cf} 
\end{figure}

The other rod used was a \textbf{3 mm outer diameter solid pultruded} rod. It is used in the steering links as well as the structural spin that runs throughout the vehicle to provide stiffness to the frame and not let the printed parts sag. It is pultruded, meaning it does not consist of carbon fibers but of chopped carbon bits held by epoxy. It is comparatively less stiff but still very strong. It consists of "toe" and no "twill". \\

\begin{figure}[H]
    \centering
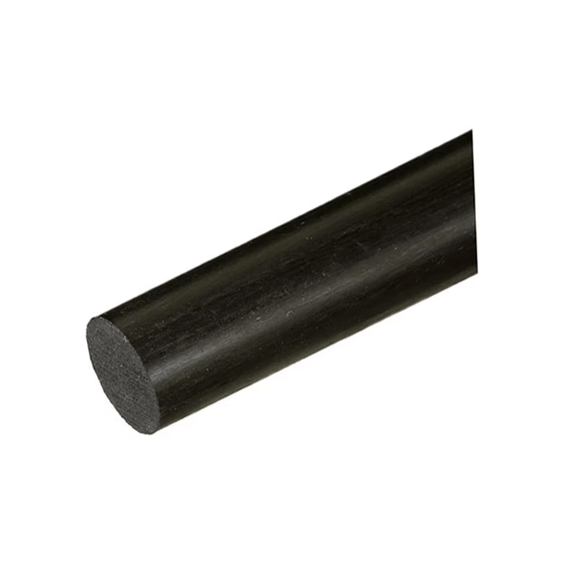
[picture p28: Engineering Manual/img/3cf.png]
    
    \caption{The 3 mm PultrudedCF rod.}
    \label{fig:3mm_cf} 
\end{figure}

\subsection{Wheels}

\subsubsection*{Design Constraints \& Diameter Selection}
The selection of the wheel diameter is one of the most critical foundational decisions in the vehicle's architecture, as it directly locks in ground clearance, overall vehicle height, wheelbase geometry, and internal volume distribution. \\

Two strict physical constraints dictated the wheel sizing. First, the maximum overall height of the vehicle had to remain strictly under $80\,\text{mm}$ to ensure the YD-LiDAR X4 Pro maintains an unobstructed $360^\circ$ laser line sweep at a height of $90\,\text{mm}$, which is well clear of the $100\,\text{mm}$ arena perimeter walls. Second, the ground clearance had to accommodate the Surpass Hobby 3674 rear drive motor, which has an outer diameter of $36\,\text{mm}$. To prevent the motor housing from dragging against flat ground without suspension, the wheel diameter had to comfortably exceed $36\,\text{mm}$. \\

In previous competition iterations, $65\,\text{mm}$ wheels were utilized. However, they proved excessively large, creating severe vertical congestion between the drive motor, chassis braces, and LiDAR platform. Consequently, a target wheel diameter of $\approx 50\,\text{mm}$ ($48$--$50\,\text{mm}$) was selected, offering adequate ground clearance for the $36\,\text{mm}$ motor while maintaining a compact vertical profile. \\

\subsubsection*{Commercial Evaluation \& Shore Hardness Selection}
Commercially available $2$-inch ($48\,\text{mm}$) FingerTech Combat Robot wheels were initially evaluated due to their high-traction tread and $40\text{A}$ durometer rating. \\

The durometer rating measures an elastomer's resistance to indentation on the Shore A scale, where lower values ($20\text{A}$--$30\text{A}$) indicate soft, gel-like compounds, and higher values ($70\text{A}$--$90\text{A}$) represent rigid plastics. A hardness of \textbf{40\text{A} Shore Hardness} represents the optimal balance for autonomous racing, providing exceptional surface traction and grip on the track mat without disintegrating or tearing under high motor acceleration torque. \\

Because $2$-inch $40\text{A}$ combat wheels were unavailable domestically in India and prohibitively expensive to import, a custom in-house casting process was developed instead. 

\subsubsection*{Manufacturing \& Polyurethane Casting Procedure}
To fabricate custom $48\,\text{mm}$ high-traction tires, a two-part casting process was established using SLA resin 3D-printed molds and PLA wheel hubs. The Polyurethane selected was a 2 part 10:4 ratio 40A mixture made by Aditya Silicone. Standard teflon based mold release spray was used. \textit{Please ensure proper PPE and safety when working with these materials.} \\

For the core wheel hub fabrication (\texttt{Wheel Hub.step}, see Figure \ref{fig:C_W_H}), the part is 3D printed in PLA with an $18\,\text{mm}$ width. To ensure a permanent mechanical bond between the printed hub and the cast tire, the outer cylindrical contact surface is printed with a "Fuzzy Skin" texture ($0.1\,\text{mm}$ thickness, $0.2\,\text{mm}$ density), creating microscopic interlocks for the curing compound. \\

For the precision mold fabrication (\texttt{Tools/Tire Mold.step}, see Figure \ref{fig:C_W_Mold}), a two-part split mold was 3D printed using Stereolithography (SLA) resin. SLA resin was selected over FDM because its smooth surface finish eliminates layer lines, allowing clean demolding without requiring draft angles. The mold halves clamp together using four $\text{M3} \times 30\,\text{mm}$ screws, washers, and $\text{M3}$ hex nuts. \\

During the polyurethane casting phase, a two-part liquid Polyurethane elastomer formulated to $40\text{A}$ Shore hardness is mixed, degassed to remove air bubbles, and poured through the mold's entry port until liquid emerges from the riser exit port. After a $24$-hour cure cycle, the mold is unbolted, producing a balanced, high-traction polyurethane tire bonded securely to the PLA wheel hub. \\

A file called \texttt{Castings.csv} contains all the details of each and every individual castings, including Part A and Part B ratios, weights and remarks. It can be found in the \texttt{Other} folder.

\pagebreak

\section{PCB Assembly}

The first question one should ask is why use a PCB at all? Why not just use jumper wires and other modules? \\

The answer is quite simple yet complex. A Printed Circuit Board (PCB) integrates all the power management components needed into a sleek and compact form factor without a lot of wiring. The Raspberry pi has a $20 \times 2$ pin interface, which isn't very neat in it self. One can connect the individual jumpers to the header pins but it becomes VERY cumbersome very fast. Hence a PCB is almost necessary for a vehicle that can be easily serviced and is well engineered. Another major driver for this, as you will learn, comes from issues learnt from Siddesh's participation in WRO the previous year. KiCAD was used as the eCAD tool to design the PCBs.\\

\subsection{Purpose}

When participating in WRO 2025, the SD Card we were using failed on us the day before the final competition. It was corrupted and the Raspberry Pi would not boot up at all. Turns out the issue was that that the Raspberry Pi was constantly undervolting under load. We had attempted to add a capacitor before the competition to resolve the issue, but the effort proved futile. Upon reviewing the logs, we confirmed that these undervoltage events were, in fact, what caused the SD card to fail. The buck converter was rated for $5$V at a nominal current of $3$A and a burst current of $5$A. Yet the Raspberry Pi wouldn't boot. \\

The Raspberry Pi needs a voltage higher that just $5$V. It needs a voltage of about $5.15$V to prevent the undervolting issue we had seen earlier. We searched the market for a buck converter capable of providing the $5.1$V and $3$A but I couldn't find a suitable option. Hence it was determined that a custom solution was needed. \\

Hence the following considerations for the PCB were formed $\rightarrow$

\begin{enumerate}
\item Deliver $5.15$V to the Raspberry Pi and have a continuous rating of atleast $3$-$5$A to power the LiDAR as well.
\item Deliver $8$V to the servo motor at $2$A.
\item Provide a better hardware interface than the $20 \times 2$ connector for the Servo and ESC.
\item Be compact and reliable.
\item Have additional expansion ports for Time Of Flight Sensors, and more Servos.
\item Integrate the power switch and start switch, along with indicator LEDs needed for the rules on to the board.
\item Look good!
\end{enumerate}

\subsection{Form Factor}

The first thing to decide after deciding the purpose is to decide the form factor of the PCB. This in turn, will decide where the PCB will live. \\

The best form factor is having the PCB as a hat above the Raspberry Pi itself. This is because of the following reasons $\rightarrow$

\begin{enumerate}
\item There is a relatively large space above the Raspberry Pi, somewhere about 65 mm $\times$ 56 mm.
\item A simple header pin board can be added to the PCB, meaning it will directly interface with the header pins on the Raspberry Pi. This would eliminate the need for adding wires between the Pi and the PCB, ensuring efficient and smooth power distribution and connections.
\item It would provide ease of maintenance to the PCB and uninterrupted access to the switches.
\end{enumerate}

\subsection{Selection of the ICs}

Due to the custom need for the $5.15$V and a lack of existing modules, a custom voltage converter module would have to be implemented on the PCB hat. Since we were already using SMD (Surface Mount Device) components for the $5.15$V PCB, we decided to integrate the $8$V part as well on the PCB itself rather than have a separate module. \\

We use buck converters, which are a form of switching regulators rather than using linear regulators. Although linear regulators provide the smoothest possible voltage, they dissipate the remaining energy as heat, and hence are very inefficient and only good for low power applications where the voltage difference between the input and output is very low. However, we need the exact opposite. We need to draw an insignificant current and our voltage difference between the input and output is substantial. Hence we use switching regulators. The only downside is that they do not have a clean voltage output as they use a MOSFET to switch at between $0$V and battery voltage at high frequencies. This can be compensated for using good design and with adding filtering capacitors at the output.

\subsubsection{The 5.1V Rail}

The LM61460 from Texas Instruments was chosen as the switching regulator due to its size and the fact that it has a continuous limit of $6$A. It is also ideal because it has symmetric switching nodes and in built MOSFETs, which reduce noise. \\

\begin{figure}[H]
    \centering
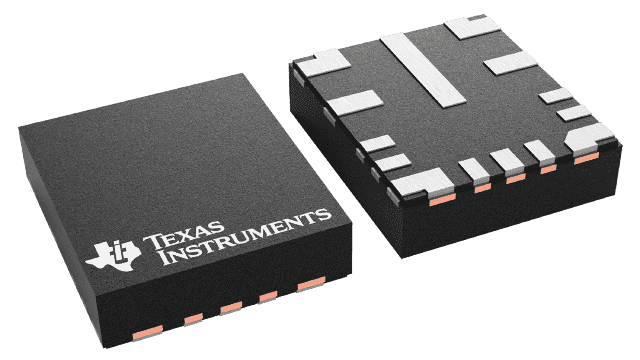
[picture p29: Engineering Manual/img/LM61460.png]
    
    \caption{The LM61460 in the VQFN-HR package.}
    \label{fig:LM61460} 
\end{figure}

The values for the schematic were obtained using the TI Workbench.

\subsubsection{The 8V Rail}

The TPS62932 from Texas Instruments was chosen as it is incredible small and has a current rating of $2$A. It also has an in built MOSFET in its incredible tiny package of just 2.1 mm $\times$ 1.6 mm.

\begin{figure}[H]
    \centering
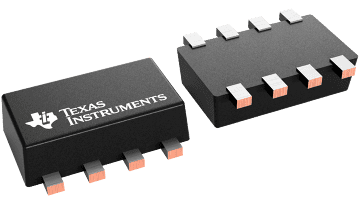
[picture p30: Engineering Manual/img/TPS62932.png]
    
    \caption{The TPS62932 in the SOT-583 package.}
    \label{fig:TPS62932} 
\end{figure}

The values for the schematic were obtained using the TI Workbench.

\subsection{The Schematic}

The first stage of the PCB development process is creating the schematic; the wiring diagram for all the connections. The first step is to add all the individual components that are used, the Raspberry Pi, the buck converter ICs, the motors, the LEDs, the switches, the power connectors and any other I/O that maybe needed. \\

The switching regulators need additional hardware, such as resistors and capacitors along with an inductor. The value of these components decide what voltage you get at the output. To find these values, the TI workbench tool was used. The TI workbench allows one to configure the parameters and then produces a schematic (Figure \ref{fig:TI_WB}). This is then used to set the value and the connections of the SMD components. \\

\begin{figure}[H]
    \centering
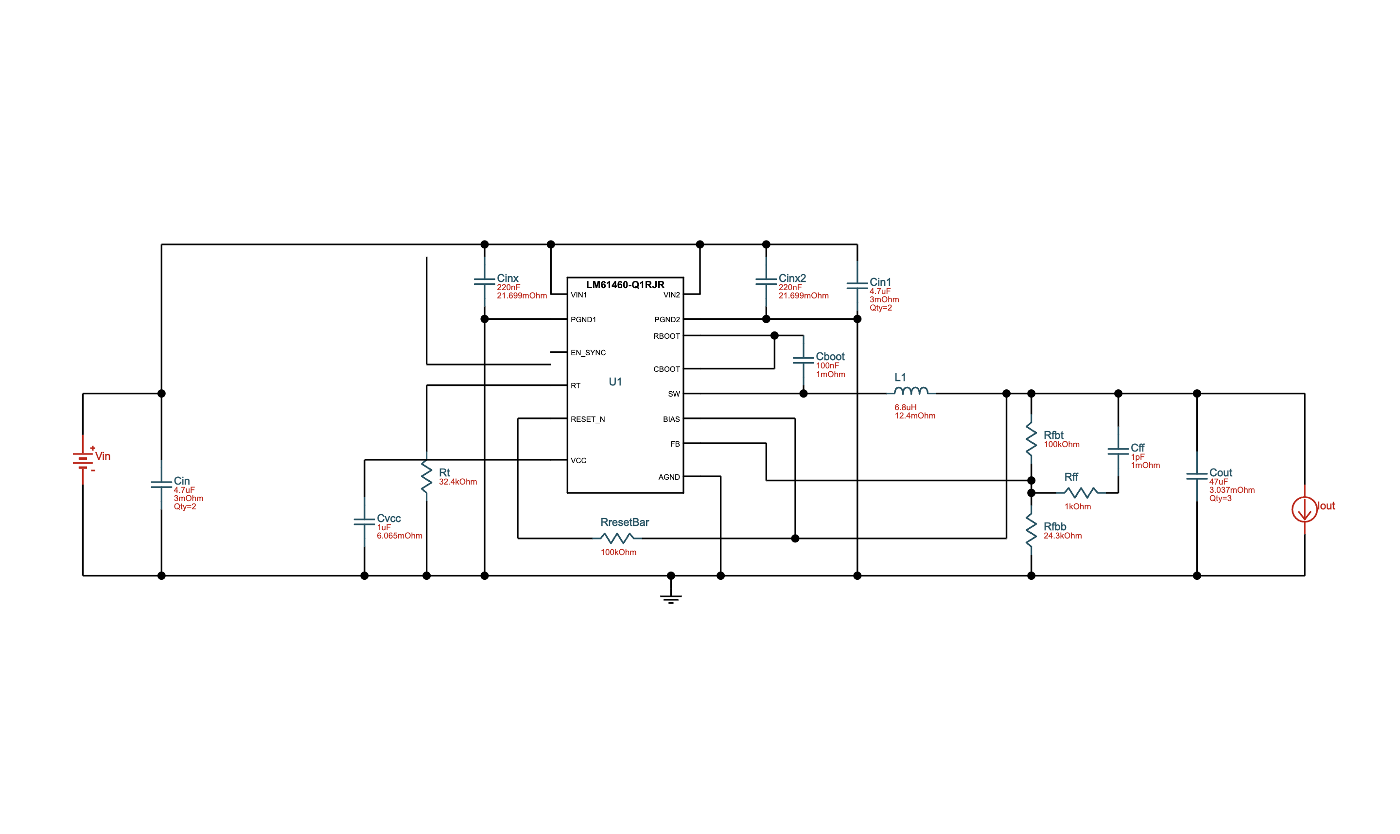
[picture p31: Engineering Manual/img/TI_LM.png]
    
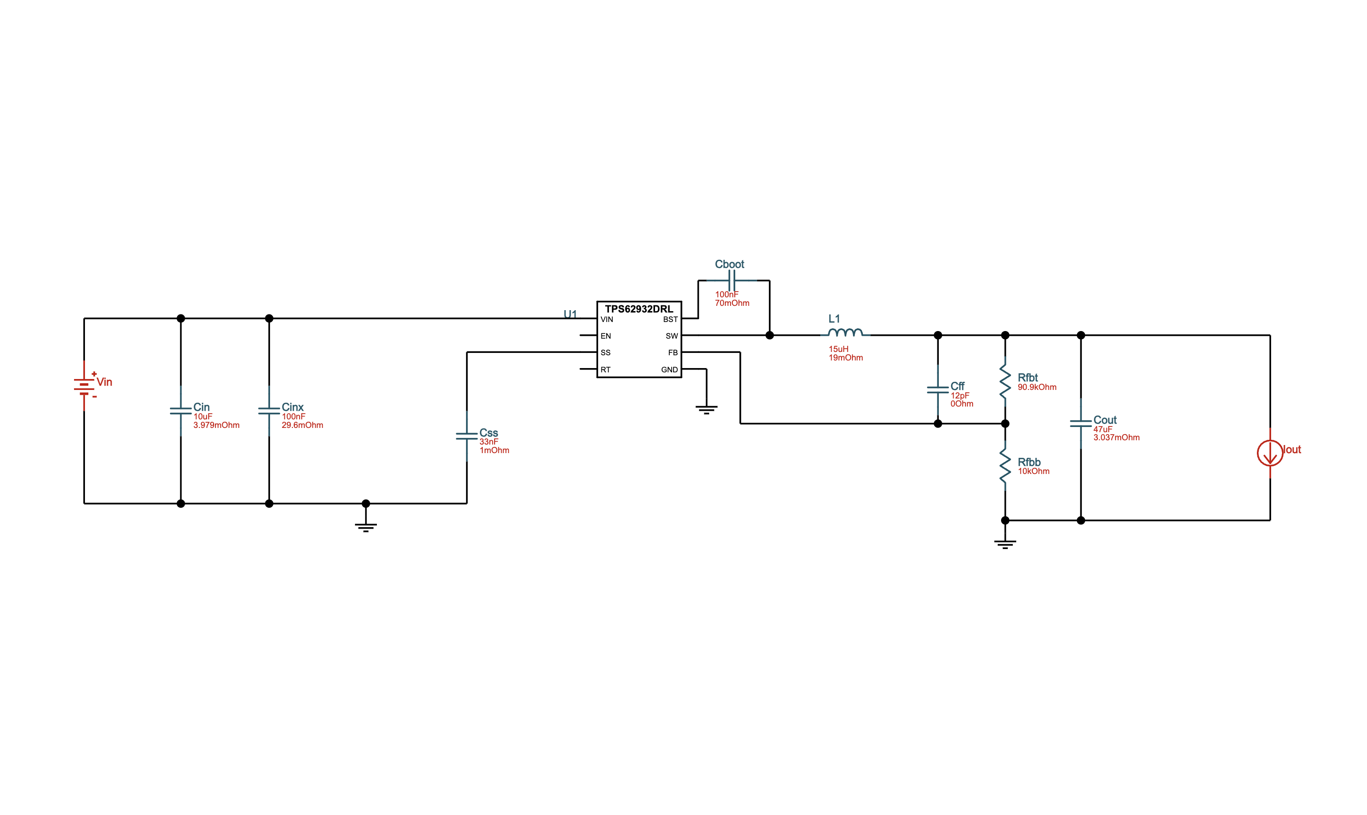
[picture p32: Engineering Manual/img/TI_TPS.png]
    
    \caption{The files for the schematic given by TI Workbench.}
    \label{fig:TI_WB} 
\end{figure}

The schematic (Figure \ref{fig:Schematic}) created is in 3 pages. The main page has the XT30 power connector input and the power switch. The Raspberry Pi page consists of the Raspberry Pi, the sensors and I/O devices. The power page consists of all the power regulation circuitry. It also has 2 additional electrolytic capacitors, one $220 \mu \text{F}$ and the other $270 \mu \text{F}$. They both act as decoupling capacitors for the Raspberry Pi and the servo respectively. They ensure that when there are load spikes from either devices, the Raspberry Pi booting or the servo starting to move, the spike does not reach the ICs and is handled locally.

\begin{figure}[H]
    \centering
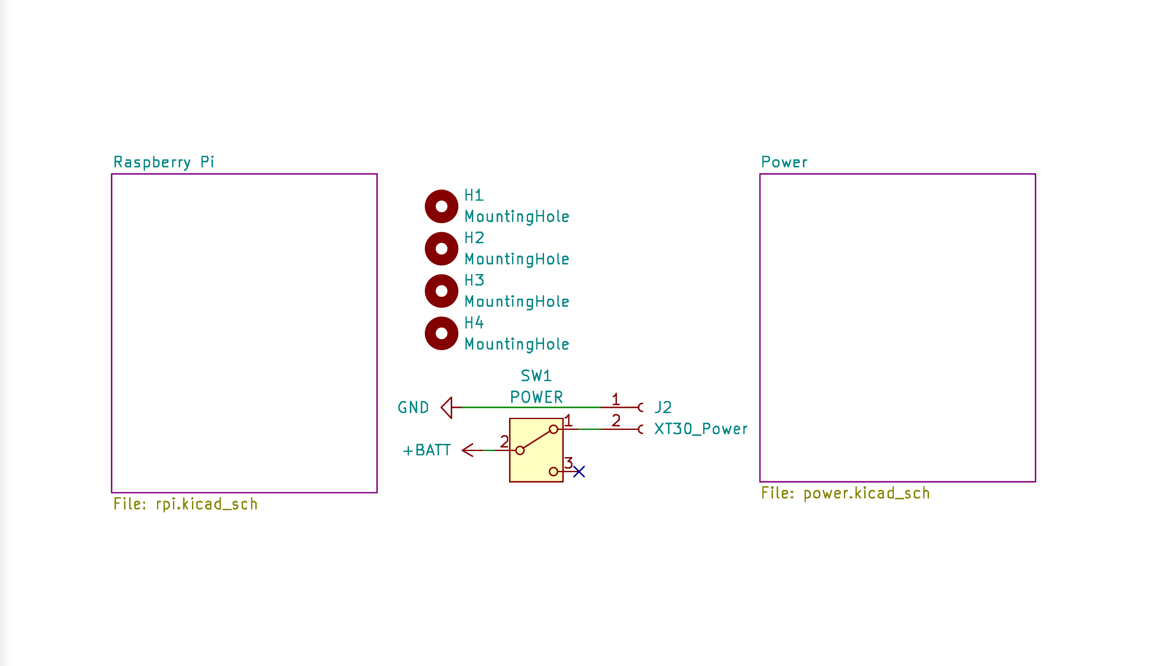
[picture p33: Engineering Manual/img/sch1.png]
    
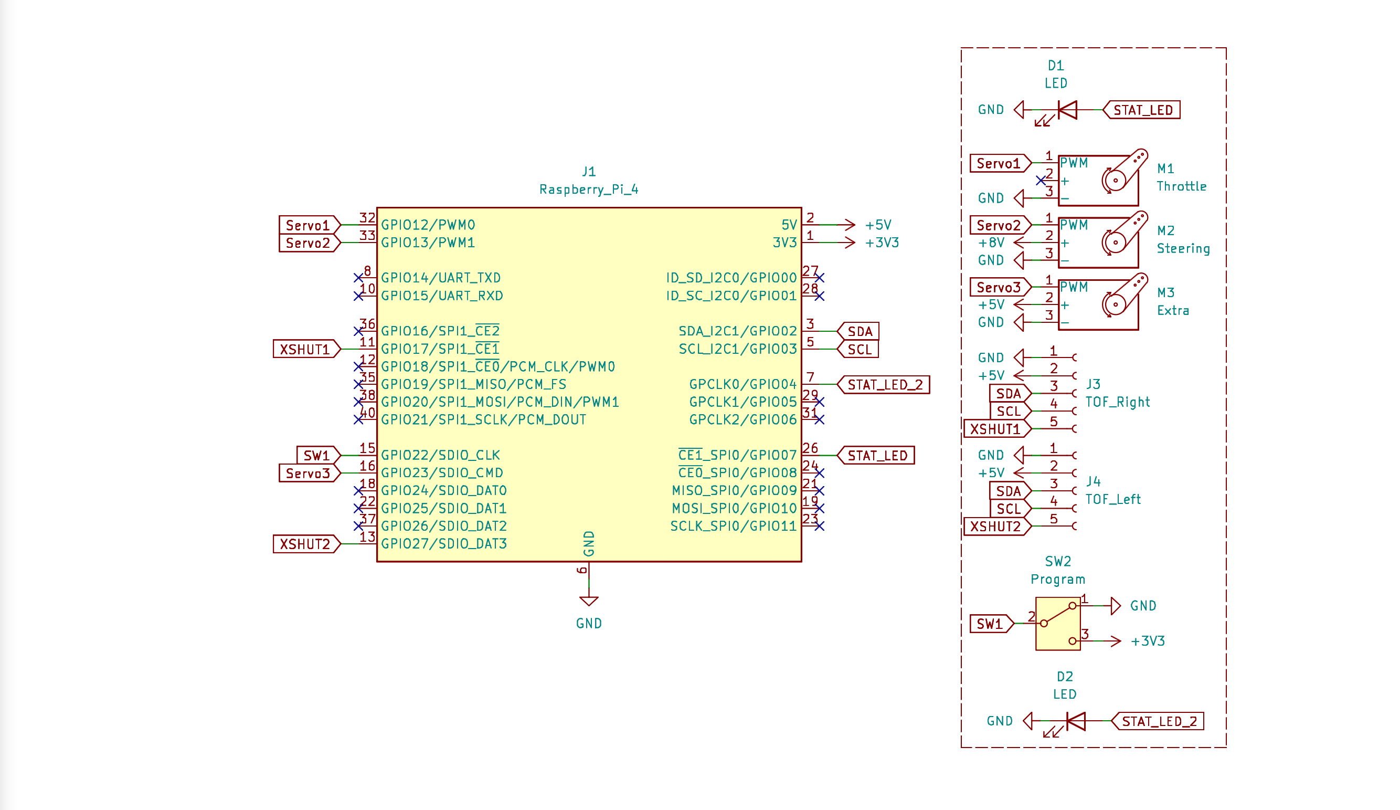
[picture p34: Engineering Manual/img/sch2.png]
    
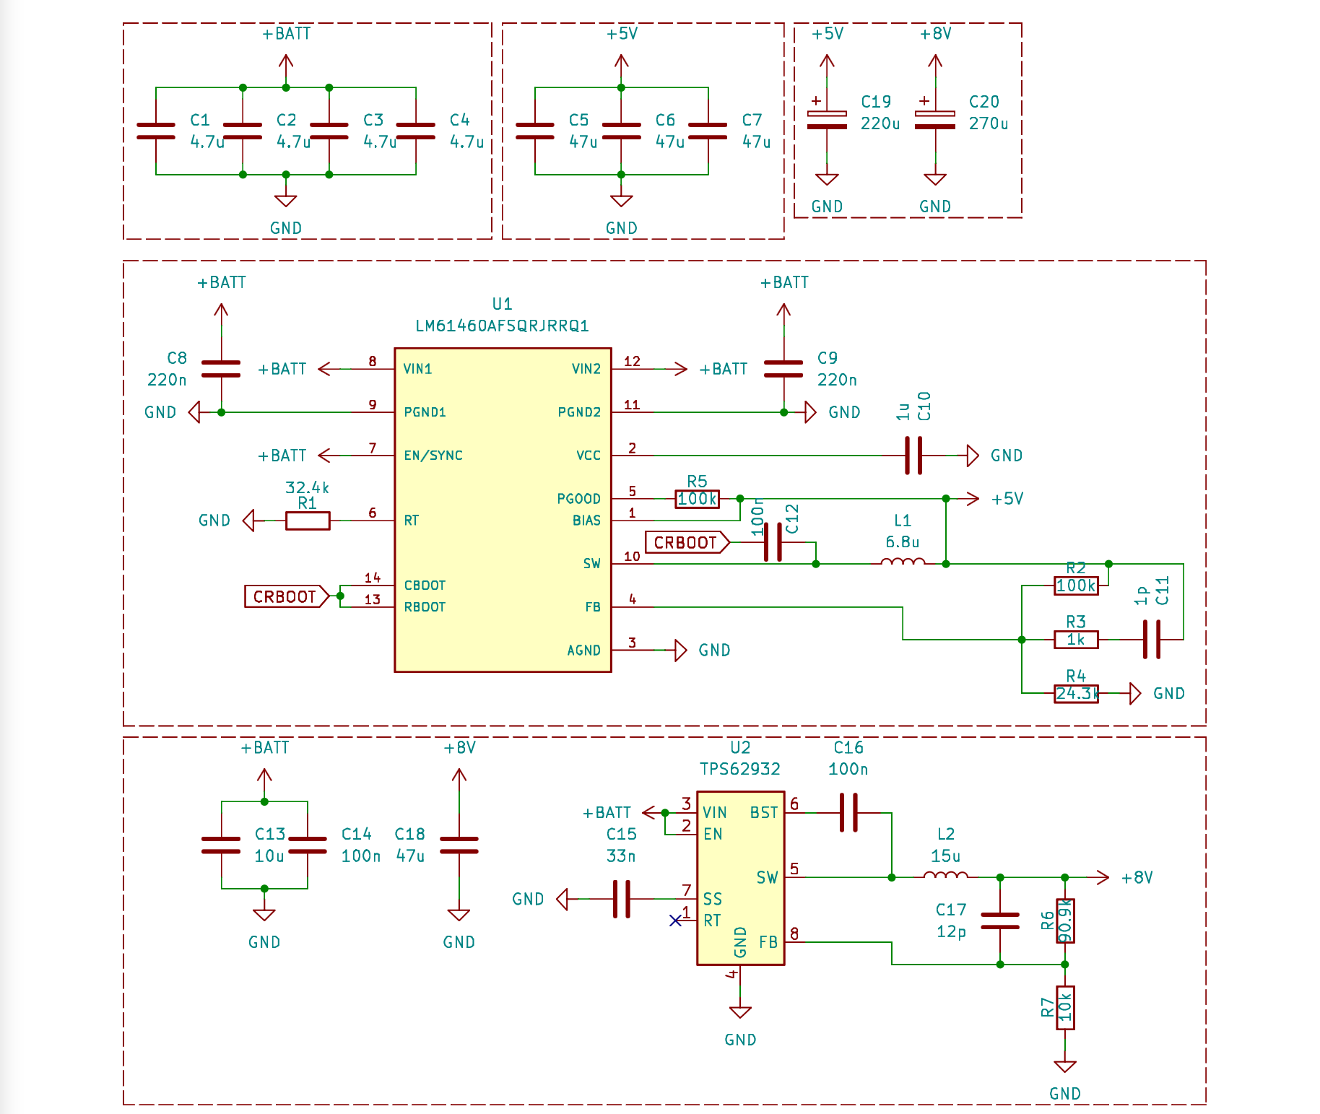
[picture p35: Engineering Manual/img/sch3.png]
    
    \caption{The 3 pages of the schematic.}
    \label{fig:Schematic} 
\end{figure}

The PDF for the Schematic can also be found in the PCBA folder. The BOM for all the parts is also available there, along with the manufacturer used.

\subsection{The Layout \& Routing}

This step is very crucial, it is responsible for how well the components interact with each-other and determines how clean your output voltage is. A \textbf{4 layer board} was chosen. This was done as it would make the routing easier across multiple layers and because a 4 layer stack up is recommended in the LM61460 data sheet. \\

All the SMD components would be place on one side of the board so that the board could be assembled on a hot plate. This would also aid with the ease of assembly. The following is the stack up $\rightarrow$

\begin{enumerate}
\item Layer 1: It carries much of the important \textbf{signals}, especially for the buck converters.
\item Layer 2: A solid \textbf{Ground} plane to reduce EMI and act as a fast return path of the top player.
\item Layer 3: The \textbf{Power} plane consisting of the input voltage, $5.15$V and $8$V.
\item Layer 4: A \textbf{Ground} plane that also carried some of the \textbf{signals} from the Raspberry Pi.
\end{enumerate}

The first thing to do is create the board outline. A rounded rectangle with length $65$mm, height $56$mm and a corner radius of $2$mm was chosen. A $6$mm notch was then removed from the bottom right of the board to allow the camera ribbon cable to pass through. Figure \ref{fig:Outline} shows the shape of the board.

\begin{figure}[H]
    \centering
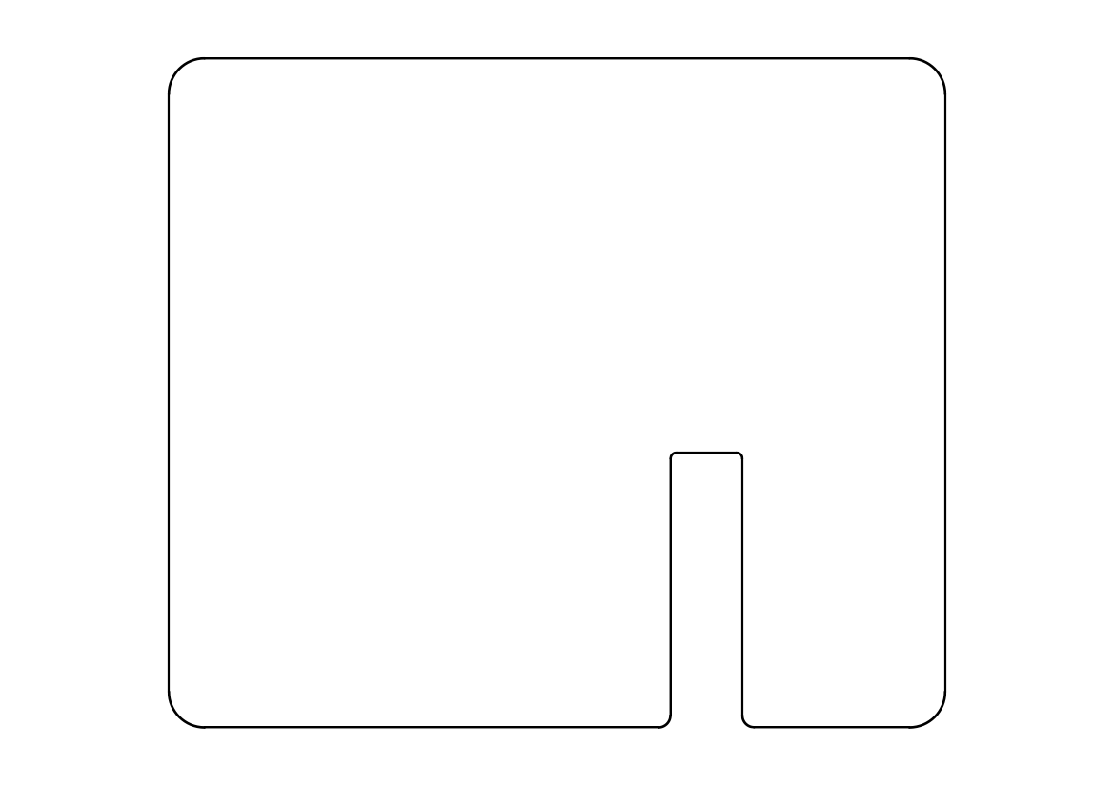
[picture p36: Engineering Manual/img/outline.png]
    
    \caption{The "edge cuts" layer.}
    \label{fig:Outline} 
\end{figure}

After this, the fixed components are place, such as the mounting holes for the board and the $20 \times 2$ female header pin that connects to the Raspberry Pi. These need to be incredibly precise as they are the locating hardware for the hat to connect on to the Raspberry Pi. M$2.5$ holes are used.

\begin{figure}[H]
    \centering
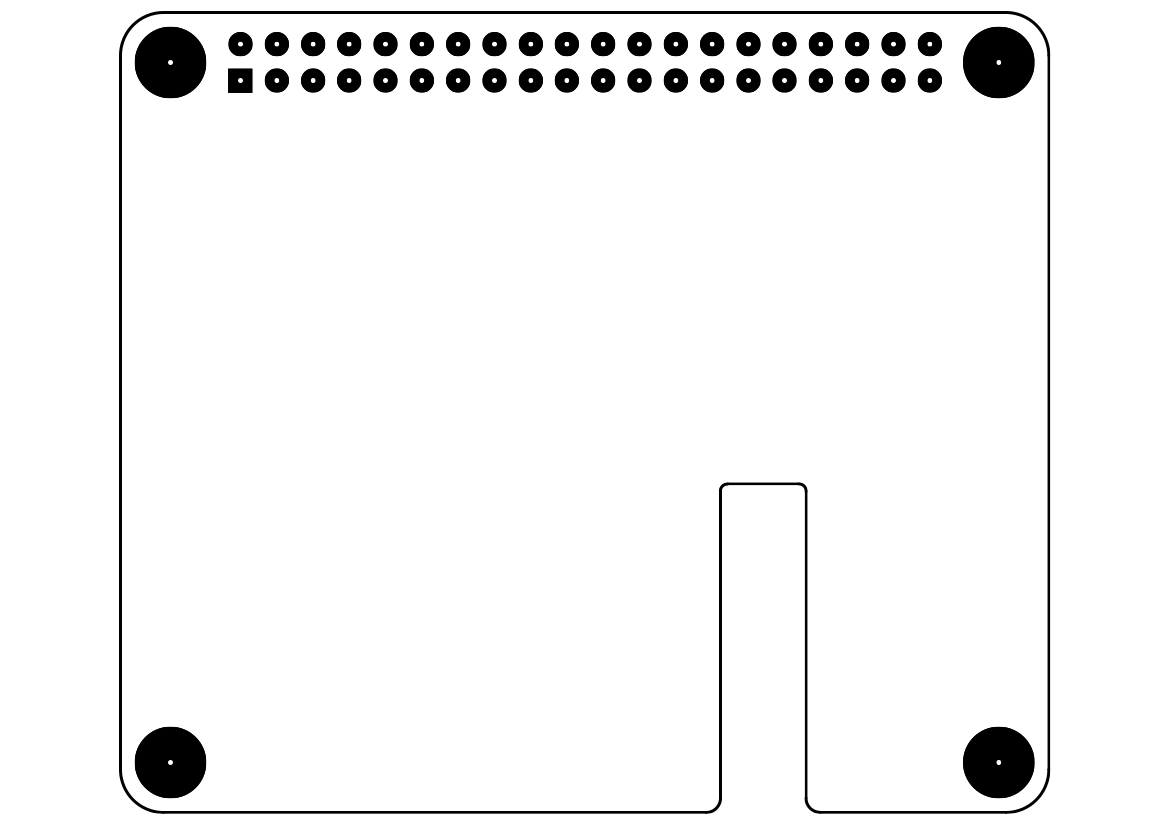
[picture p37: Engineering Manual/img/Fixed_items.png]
    
    \caption{The fixed items layer.}
    \label{fig:Fixed_Items_PCB} 
\end{figure}

The next part is the most cumbersome. All the physical parts need to be laid out in a manner that ensures the most ideal connections possible. The 3 main current loops; ON-State Current Loop, OFF-State Current Loop and The "Hot Loop"; of the buck converter need to be kept as short as possible. Since we are using a symmetric buck converter, it also needs to be made sure that the power lines to both sides are as similar as they can be. The path between the switching node and the inductor needs to be as short as possible. All the connectors need to accessible. \\

For this reason, the power connector (XT30) and the power switch were placed on the right side. The switching circuitry was spread around the middle. The second switch and the connectors for the motor and servo were kept on the left side. The electrolytic capacitors were placed as close to the outputs as possible. The LEDs were also placed in the middle. The extra components, such as the connectors for the 2 ToF sensors and an extra PWM connector were kept on the bottom and bottom right respectively. Figure \ref{fig:Layout} shows the layout of the final board. It is fairly crammed but a lot more items, such as more LEDs, Current and Voltage sensing and a CAN BUS port can also be added in the future.

\begin{figure}[H]
    \centering
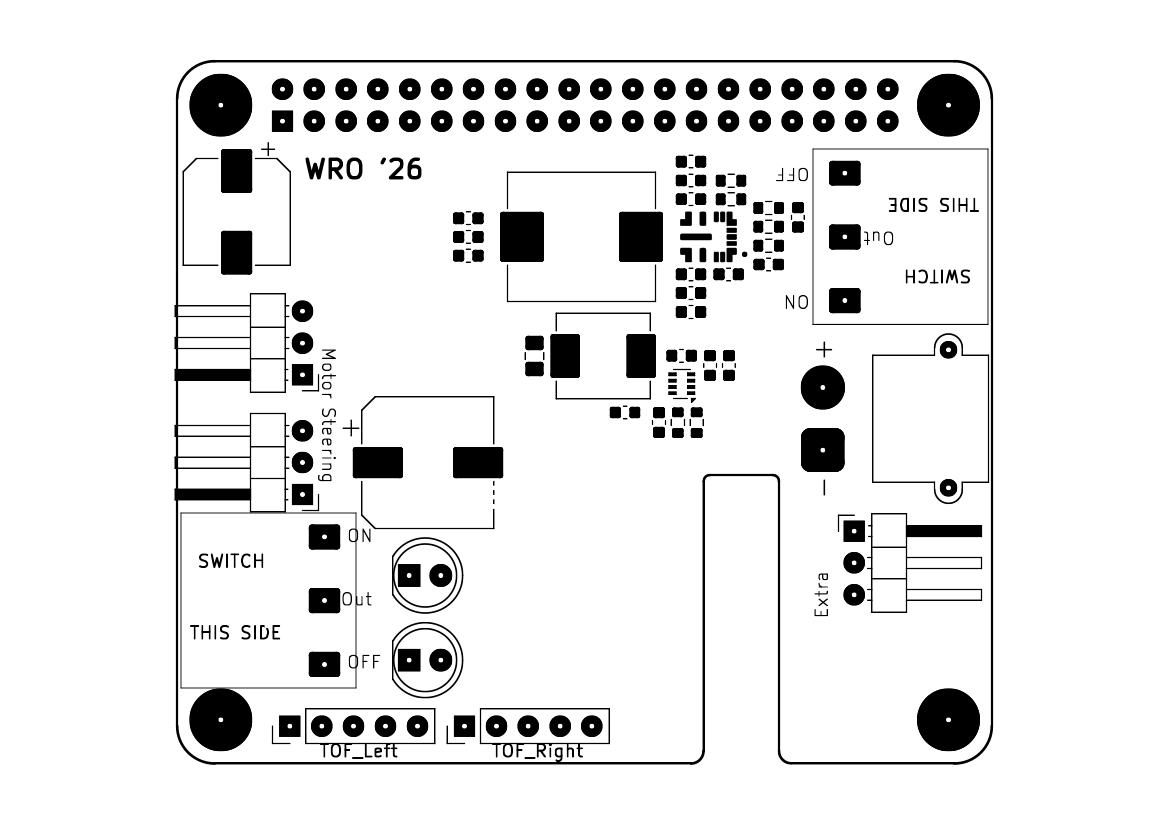
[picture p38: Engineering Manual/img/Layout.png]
    
    \caption{The final layout depicting the placement of all the components.}
    \label{fig:Layout} 
\end{figure}

Figure \ref{fig:Layers} shows the actual copper layers as they are. Copper pours are preferred whenever possible. They also help with thermal management. It was made sure that there were no wires beneath the two inductors to make sure all the signal traces are as clean as possible.

\begin{figure}[H]
    \centering
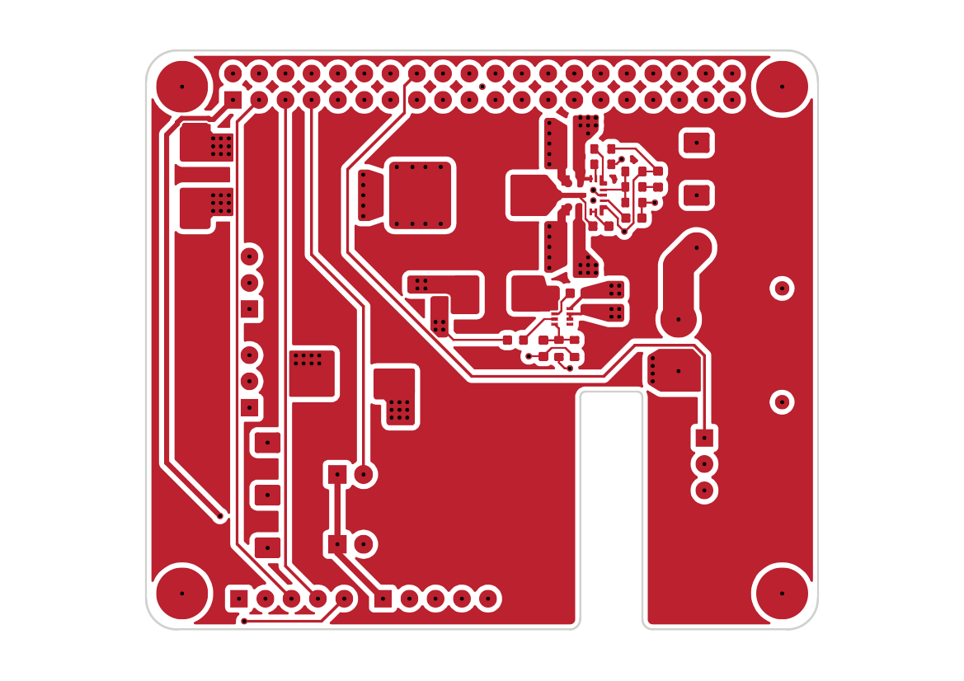
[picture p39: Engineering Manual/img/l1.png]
    
\end{figure}

\begin{figure}[H]
    \centering
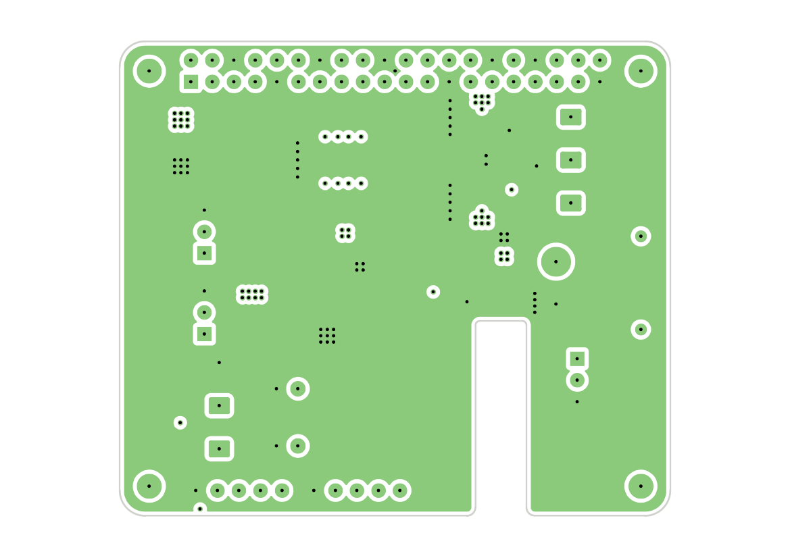
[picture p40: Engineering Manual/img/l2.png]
    
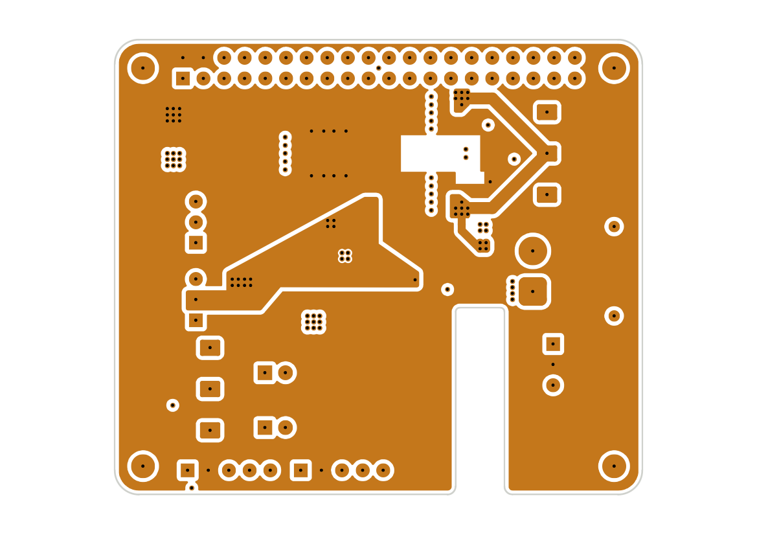
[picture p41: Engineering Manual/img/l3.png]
    
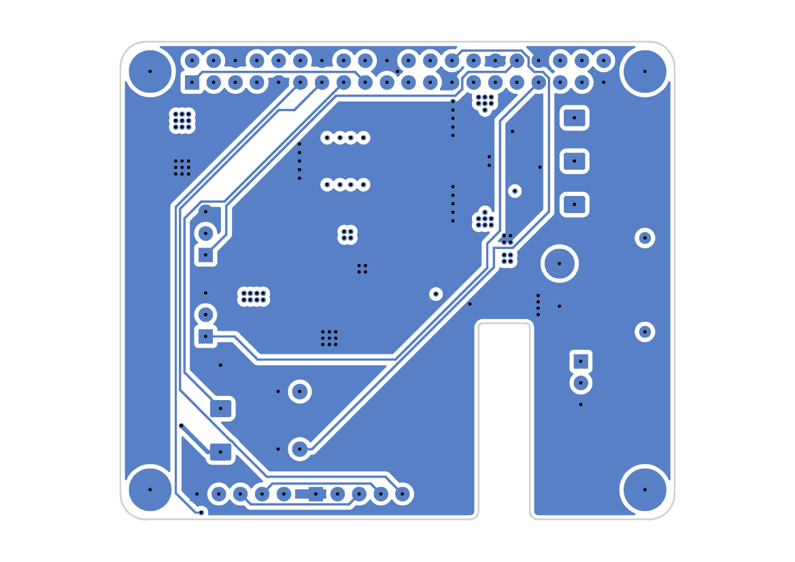
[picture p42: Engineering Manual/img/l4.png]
    
    \caption{The 4 copper layers. Layer$1$ $\rightarrow$ $4$.}
    \label{fig:Layers} 
\end{figure}

Some art work and quotes were added to the free space to ensure complete utilization and occupation of left over space. A black solder mask was chosen. Figure \ref{fig:KiCAD_Render} show the PCB rendered in the KiCAD 3D viewer. The contribution for the art work goes to M.C. Escher.

\begin{figure}[H]
    \centering
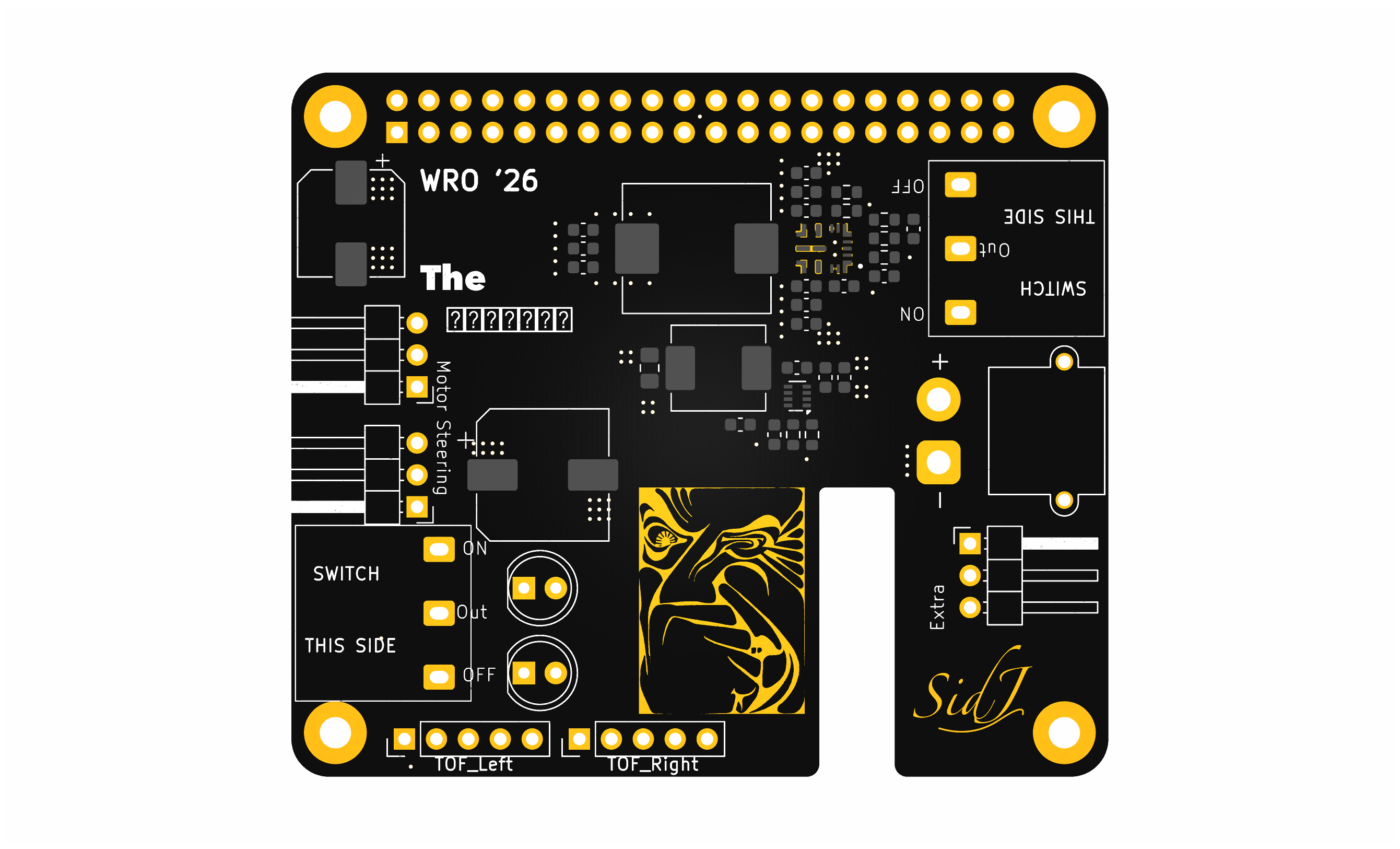
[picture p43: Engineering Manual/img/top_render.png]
    
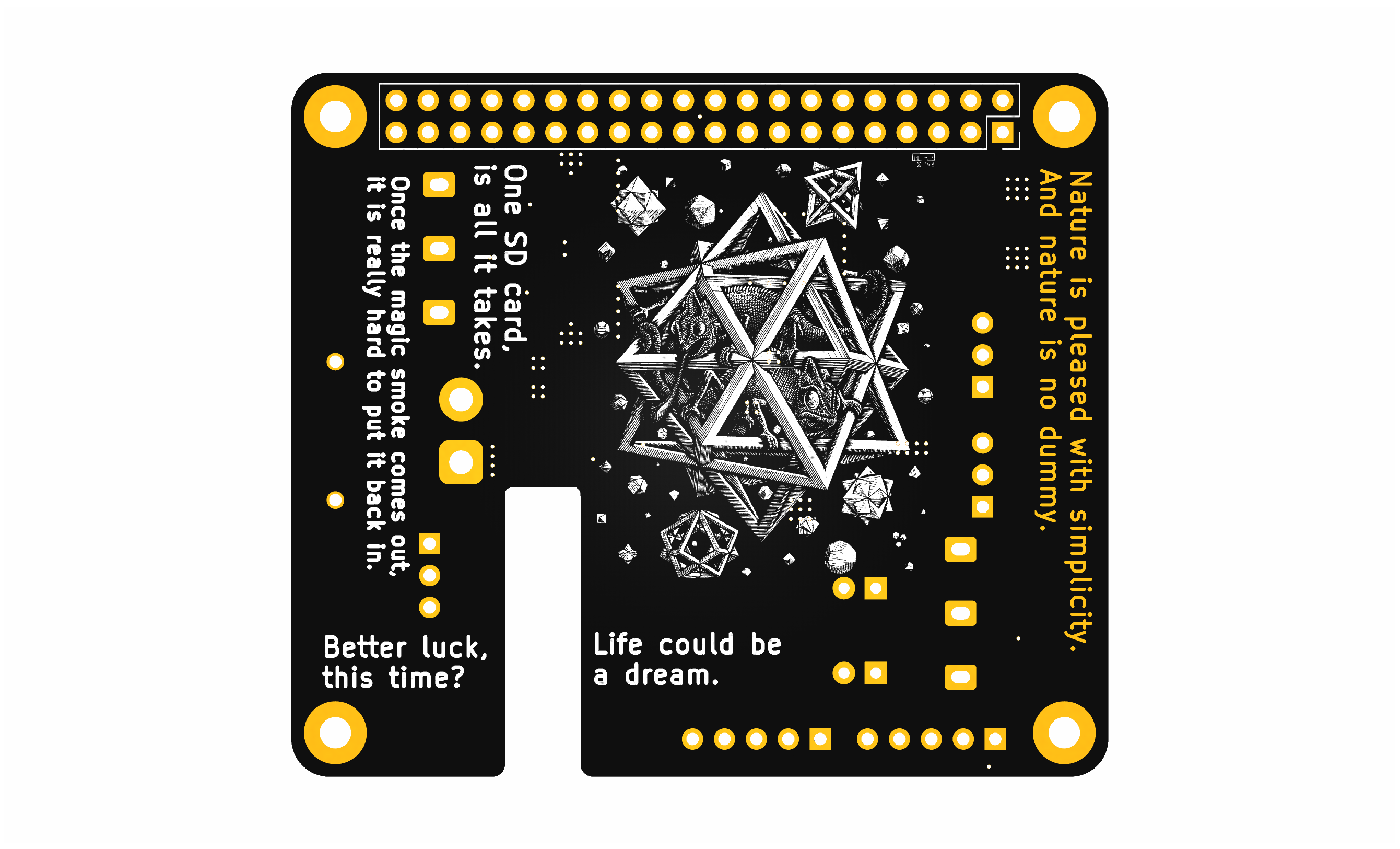
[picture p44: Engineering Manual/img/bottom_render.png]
    
    \caption{The rendered PCB.}
    \label{fig:KiCAD_Render} 
\end{figure}

The PCB was manufactured by JLC. JLC was chosen due to their lower cost for black solder mask compared to Indian manufactures. The following are the basic parameters:

\begin{enumerate}
\item Base material: FR4
\item PCB Thickness: $1.6$mm
\item PCB Color: Black
\item Silkscreen: White
\item Material Type: FR4 TG135
\item Surface Finish: Lead Free HASL (Hot air solder leveling)
\end{enumerate}

\subsection{Assembly}

The assembly was done by hand. 0603 class components are not too hard to place by hand. Alternatively, assembly can be done by the manufacturer as well. \\

A stencil was used to apply the layer of $183^\circ$ C solder paste on to the board with the help of an old credit card. The "Interactive Html Bom" plugin (Figure \ref{fig:IHBT}) was used to aid with assembly. The plugin creates a interactive html file that can be used to figure out the placement of the components. Alternatively, the PCB and schematic editor can itself be used to figure the placement out but using the plugin is recommended do to its convenience. Once the components have been laid out, a final visual inspection can be carried out. \\

\begin{figure}[H]
    \centering
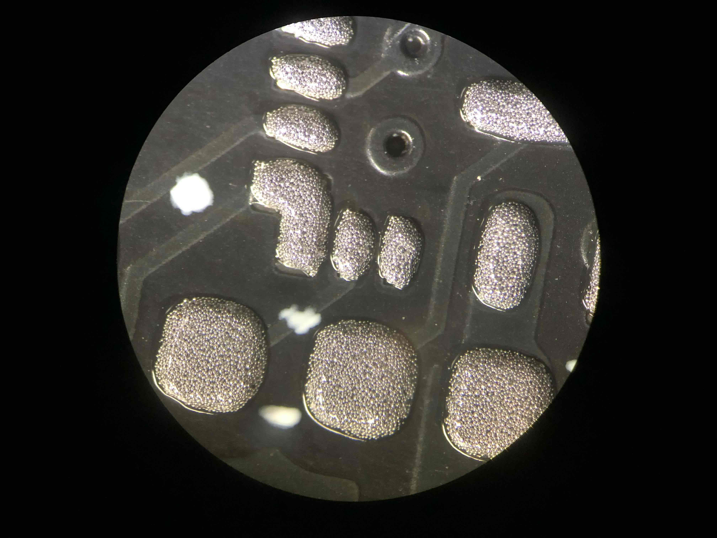
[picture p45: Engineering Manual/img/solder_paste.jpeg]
    
    \caption{The solder paste on the pads after being applied with a stencil.}
    \label{fig:solder_paste} 
\end{figure}

The boards can then be re-flowed on the hot plate. It is recommended to follow the heat curve of the solder paste being used. If the plate available does not have the ability to follow a curve, let the board heat soak at about $50$-$80^\circ$ C below the melting point of the solder paste for about 1-2 minutes to let the flux activate before increasing the temperature to its final point. \\

Our hot plate did not have the feature to follow the heat curve so we let our boards soak at $130^\circ$ C for 90 seconds after increasing the temperature to $195^\circ$ C till all of the paste re-flowed and waited 30 seconds more before taking the boards off the hot plate. 

\begin{figure}[H]
    \centering
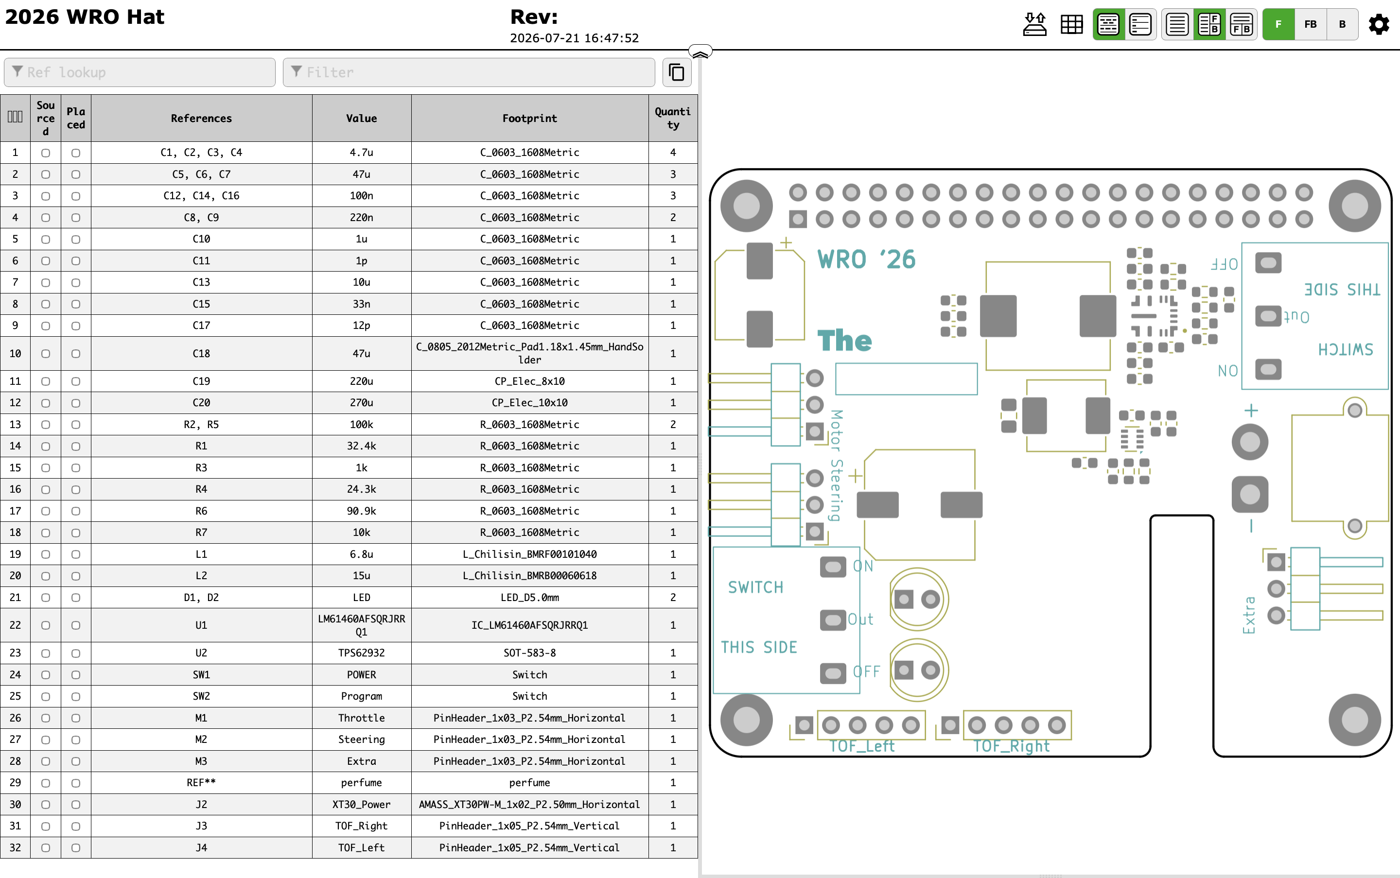
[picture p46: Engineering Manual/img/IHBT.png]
    
    \caption{The Interactive HTML BOM Tool.}
    \label{fig:IHBT} 
\end{figure}

The HTML file generated by the plugin can be found in the PCBA folder along with the BOM. \\

Once this is done, the through hole components; like the switches, the power connector and the $20 \times 2$ header connector; can be soldered on to get the final board.  \\

\textbf{Note:} Please refer to the next subsection, Mistakes \& Errors before powering on the board. There is a 1000 $\mu$F capacitor to be added between the output of the switch and GND.

\subsubsection{Advice}

The following is the recommended order for the placement of the components $\Rightarrow$

\begin{enumerate}
\item U1
\item U2 (be careful, some wiggling around is needed)
\item C8, C9
\item C1, C2, C3, C4
\item C5, C6, C7
\item C18
\item R1
\item R2, R5
\item R3
\item R4
\item C10
\item C11
\item C13
\item C12, C14, C16
\item C15
\item C17
\item R7
\item R6
\item L2
\item L1
\item C19
\item C20
\end{enumerate}

\subsection{Mistakes \& Errors}

The first iteration, \textbf{V1.0}, had a fatal flaw. During the schematic design, the enable pin of the LM61460 was connected to ground. The enable pin needs a voltage of greater than about $3$V. This mean that the chip would be in the "shutdown mode". This mean it would not work at all. \\

To attempt fix this issue, the trace from the GND via to the EN pin was cut off using a razor blade. A thin copper wire (32 AWG) was then added very carefully between the VIN and the EN pad. Typically, this is called a "\textbf{bodge}" (Figure \ref{fig:bodge}). This turned out to be very unsuccessful. This was because of the Package of the IC and the microscopic, but still substantial thickness of the wire. The VQFN package has flat pins at the bottom that interface with the surface directly (Figure \ref{fig:LM61460}). This meant that while the wire was fairly thin, its thickness meant that not all the pins of the IC made contact with the PCB. It was sort of like a see saw. Another attempt was made with a thinner strand of wire, about a third of the diameter but that was also unsuccessful. \\

Hence the decision was made to re order a new set with the fixed connections, \textbf{V1.1}. The original error was traced down to a mistake in copying the schematic from TI workbench to the KiCAD schematic editor. \\

\begin{figure}[H]
    \centering
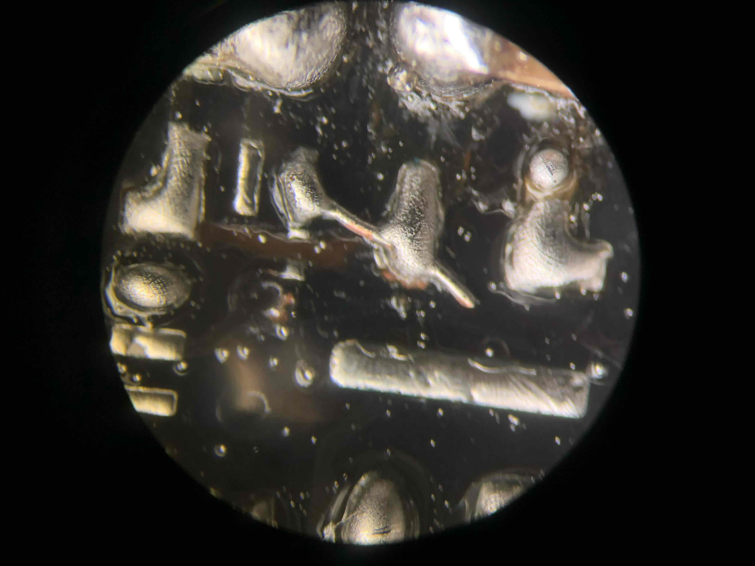
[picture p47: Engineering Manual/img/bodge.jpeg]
    
    \caption[The Bodge Wire.]{The brown area on the top right of the copper wire represents the cut out trace.}
    \label{fig:bodge} 
\end{figure}

The newer version, \textbf{V1.1} was assembled successfully and worked flawlessly, providing $5.15$V to the Raspberry Pi as intended. During hardware testing, when using the switch to power on and off the Raspberry Pi, the LM61460 chip, literally, burst into flames and released the magic smoke. This was right as the switch had been toggled to the on position, triggering a catastrophic hardware phenomenon known as an LC hot-plug transient spike. The wires from the battery inherently act as an inductor, and the ultra-low ESR (Equivalent Series Resistance) ceramic input capacitors on the board act as a capacitor, together forming an undamped LC resonant circuit. When the mechanical switch was flipped, its internal contacts bounced microscopically. This rapid connect-disconnect action, combined with the near-zero resistance of the ceramic capacitors, caused the sudden inrush current to ring like a bell. The voltage overshot significantly, effectively doubling the 16.8V battery input and easily punching through the 36V absolute maximum rating of the LM61460. \\

This destructive spike was further amplified by the DC bias derating of the ceramic capacitors, which temporarily lose capacitance under high voltage, forcing the transient spike even higher. The fix for this required introducing a "shock absorber" to dampen the resonant circuit. By adding a 1000 $\mu$F electrolytic capacitor directly between the output of the switch and ground, the naturally higher ESR of the electrolytic component safely dissipated the kinetic energy of the inrush current as microscopic heat. This completely arrested the pendulum swing of the LC ringing, clamping the voltage safely to the battery level and bulletproofing the circuit against future switch bouncing. \\

\textbf{NOTE:} The PCB design files do not include this fix, and it is to be implemented after.

\pagebreak

\section{3D Prints \& CAD}

The body of the vehicle is primarily made up of 3D printed parts. Onshape was the CAD package used. Extreme considerations were made when designing the vehicle. Ease of reputability, along with structural rigidity were the utmost priority when designing the parts. This was exasperate from the constraints already present when using FDM (Fused Deposition Modeling) 3D printing. \\

Tolerances for the parts were borrowed where ever possible as a foundational design principle to ensure predictable and consistent assembly. Because FDM printing is inherently prone to dimensional variations; caused by thermal shrinkage, layer lines, and extrusion inconsistencies; calculating unique clearances for every single joint is highly inefficient and risks assembly failure. \\

By standardizing and "borrowing" proven tolerance profiles (such as a baseline $0.2$mm gap for slip fits and $0.4$mm for clearance holes) across the entire CAD model, the design creates a modular, standardized system. This strategic allocation allows non-critical dimensions to absorb the printer's inherent inaccuracies. Ultimately, this prevents tolerance stack-up issues and guarantees that structural interfaces bolt or snap together seamlessly on the first print, eliminating the need for tedious manual post-processing, filing, or reprint iterations. \\

Pre-flight and Orca Slicer were the Slicers used for the conversion of the 3D files into G-Code. The utmost care was given to the parts in the design process. There are no large parts that need a massive printer to be printed. All the parts can fit on a minimum build volume of about $150 \times 150 \times 150$ mm. The whole assembly was created in Onshape to ensure parts fit together seamlessly. \\

\subsection{Layout \& Wheelbase}

To adhere to the strict volume limitations we set in the introduction, a slightly wider wheelbase was opted compared to what most competitors would probably use. This was done so that more horizontal volume could be allotted to the components without shifting them vertically. A strict horizontal width limit was put at $180$mm to ensure the $200$mm limit was not breached. The wheels where placed as far out as possible to maximize component volume and have better stability. \\

A wheelbase of $184.3$mm was chosen. A longer wheelbase would mean that the vehicle would have trouble parallel parking. The number $184.3$, may seem odd but it was derived from scaling the Aston Martin Valkyrie down to the size of the wheels being used. \\

The layout, as mentioned earlier, a Rear Wheel drive mechanism with front wheel steering was chosen. This made the layout slightly easier but it was crammed nevertheless. Figure \ref{fig:Top_main_view} shows the CAD assembly, moving top down. \\

\begin{figure}[H]
    \centering
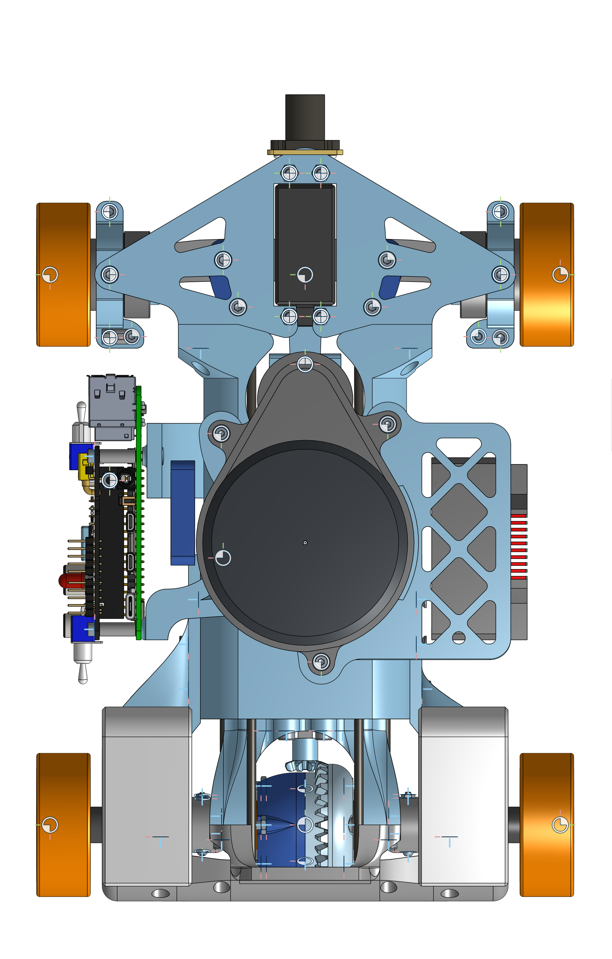
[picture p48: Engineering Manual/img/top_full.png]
    
    \caption{The Onshape assembly.}
    \label{fig:Top_main_view} 
\end{figure}

Starting at the front, we have the camera as the front most element. This is driven by the fact that the camera has a very high FOV and the best view would be unobstructed. Just behind it is the front axle. It houses the steering system and the bearings. In the center there sits the LiDAR, directly positioned on top of all the components. Below the LiDAR, with a healthy amount of spacing to prevent EMI is the motor. To the right of the motor, the ESC is mounted vertically. The Raspberry Pi is mounted on the left side of the motor. Moving further back, we reach the differential and the rear axle. The batteries sit atop the rear axle baring mounts. \\

It was critical for every single part to be accounted for. All the models were self designed. There are a few critical assemblies that need to be discussed in order. \\

\subsection{The Steering Assembly}

\subsubsection*{Front Wheel Adapter}

The steering assembly originates from two points in space, the contact points for the needle roller thrust bearings (Figure \ref{fig:needle_roller_thrust_bearing}). The bearings connect to the wheels via a rod that is capped at on end. The rod as a nominal diameter of $12$mm and a length of $38$mm. The cap at the end has a diameter of $20$mm and a width of $3$mm. The rod also has a $\diameter 2$mm hole at the end, spaced $4.5$mm from the edge of the non capped end to interface with the wheel (Figure: \ref{fig:wheel_CAD}) via a M2 screw.

\begin{figure}[H]
    \centering
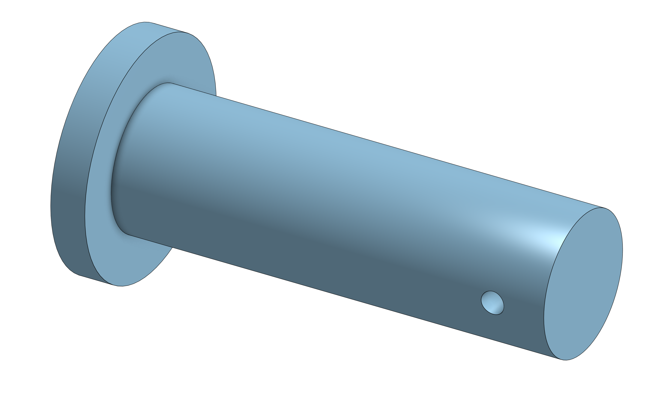
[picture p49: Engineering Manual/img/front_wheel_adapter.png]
    
    \caption{The Front Wheel Adapter Pin.}
    \label{fig:C_FWA_pin} 
\end{figure}

The pin is printed vertically, with the cap end facing down. This does spread the load across the layer lines, the load on the front wheels isn't drastic enough for one to be concerned. The part is printed with a layer height of $0.2$mm, has $3$ perimeters and a $25\%$ infill.

\subsubsection*{Steering Knuckles}

We next interface with the stationary parts of the bearing. To do this, we make a clamp style part that relies on the pressure and friction to keep the bearing constrained. We replicate the grove in the bearing as a positive feature to constrain the bearing axially.\\

\begin{figure}[H]
    \centering
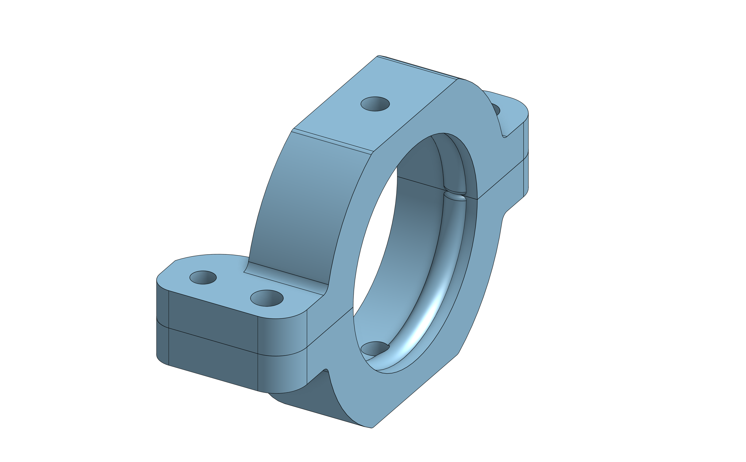
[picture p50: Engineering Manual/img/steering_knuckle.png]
    
    \caption{The Steering Knuckle.}
    \label{fig:C_SK} 
\end{figure}

To interface the two part clamp, we use two M$3 \times 12$ screws and M$3$ nuts. We flatten out the sphere at $\diameter 31$mm so that the clamps can interface with the other steering parts and rotate in the vertical axis. To do this, we add a $\diameter 2.8$mm hole on the top for a M$3$ screw. We keep the hole smaller than the screw diameter so that the screw can create the threads in the plastic part as it enters. This is done as using a heat set inset would take too much space. Also it is justified by the lower loads. We also add a $\diameter 2.5$mm hole so that a screw can be added for the steering rod interface. These would be like Steering Knuckles in a traditional car. It is mirrored to fit on the left side. \\

The part is printed with the face closest to the bearing (and image in Figure \ref{fig:C_SK}) facing down. This not only transfers the loads along the layers but also ensure a good interference fit with the bearing. The part is printed with a layer height of $0.2$mm, has $3$ perimeters and a $25\%$ infill. 

\subsubsection*{Steering Column}

The steering column consists of 4 parts (See Figure \ref{fig:C_SC}), the top brace (light blue), the bottom brace (grey) and 2 side braces (dark blue). It mounts the servo on the center of the front axle and provides interface points with the rest of the vehicle. \\

\begin{figure}[H]
    \centering
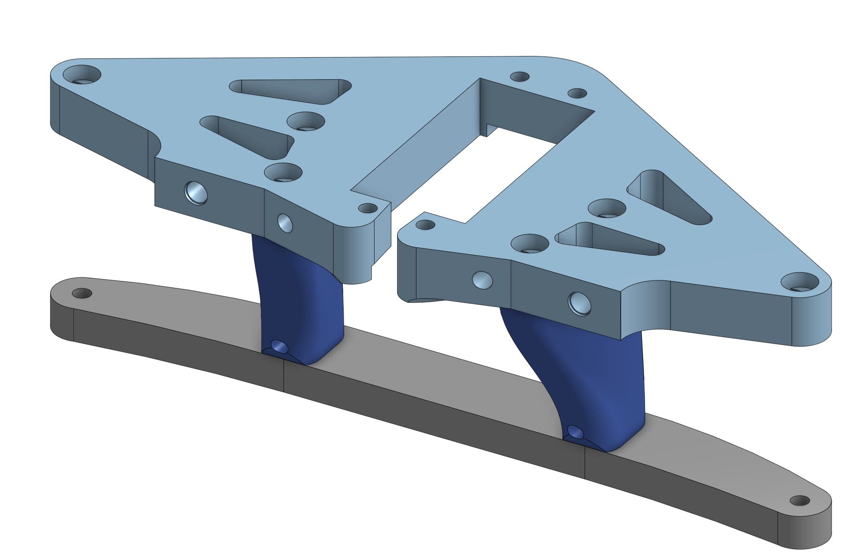
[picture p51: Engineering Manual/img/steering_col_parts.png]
    
    \caption{The Steering Column.}
    \label{fig:C_SC} 
\end{figure}

The top brace is the largest part in the steering column. It mounts the servo and the camera. The servo mounts via 4 M$3 \times 20$ screws and has a mounting pattern of $10.5 \times 48$mm. The top brace has an hole at each extreme so that it can interface with the steering knuckle. It does so by using M$3 \times 8$ screws. The holes are space $131$mm apart. The top brace has 4 additional counter bore holes that connect it with the 2 side braces. On the rear face of the mount, there are two locating holes for the carbon fiber rods that are spread apart by $36$mm. There also exists a flat face with space for 2 $M3 \times 6$ heat set inserts so that the part can interface with the rest of the body and is constrained.

\begin{figure}[H]
    \centering
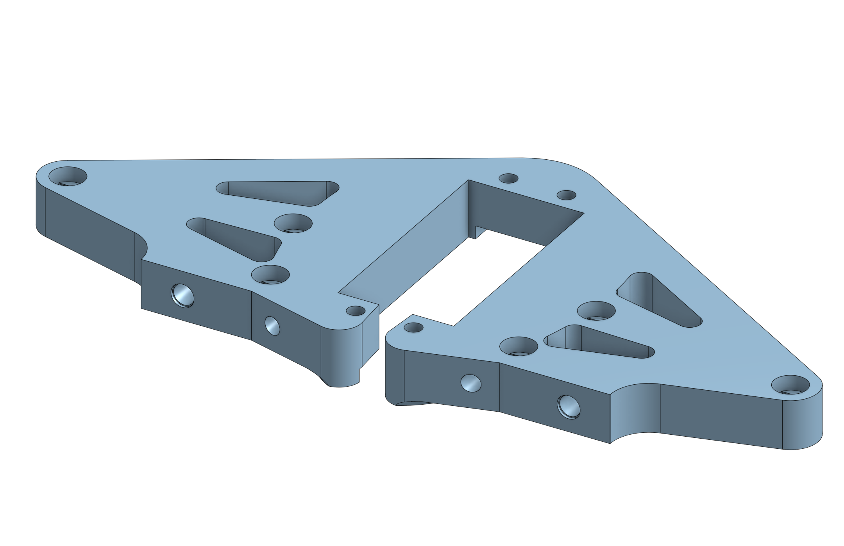
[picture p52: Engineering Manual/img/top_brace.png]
    
    \caption{The Top Brace.}
    \label{fig:C_SC_TB} 
\end{figure}

The part is printed with the top face (See Figure \ref{fig:C_SC_TB}) facing down, at a layer height of $0.2$mm, has $3$ perimeters and a $25\%$ infill. The part nominally includes features to aid with counter bore bridging but PreFlight can also be used to aid with this. \\

The bottom brace is the simplest part. It is a slightly curved piece that spans the breadth of the wheelbase. It has $4$ countersunk holes, $2$ to interface with the steering knuckles, and $2$ to interface with the side braces, using M$3 \times 8$mm countersunk and M$3 \times 10$mm countersunk screws respectively. The part is printed with the bottom face (See Figure \ref{fig:C_SC_BB}) facing up, so that the sunk bores are not printed as overhangs. It is printed at a layer height of $0.2$mm, has $3$ perimeters and a $25\%$ infill.

\begin{figure}[H]
    \centering
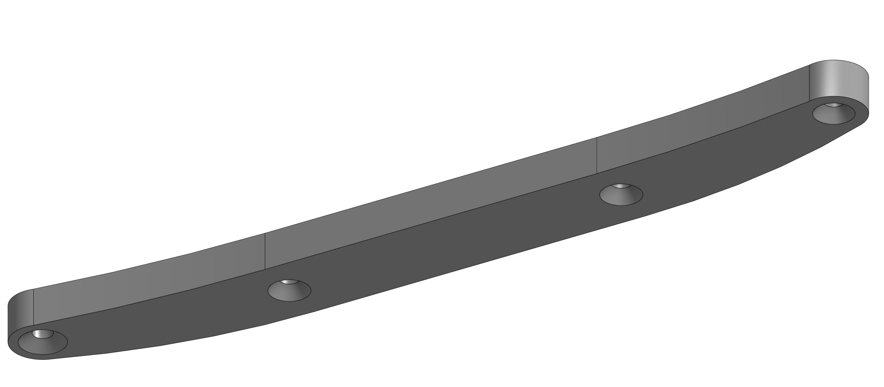
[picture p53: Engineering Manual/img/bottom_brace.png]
    
    \caption{The Bottom Brace.}
    \label{fig:C_SC_BB} 
\end{figure}

The side braces are slightly more complex in geometry as they are a product of lofts. The side braces have spaces for $2$ M$3 \times 6$mm brass heat set inserts on the top, and $1$ M$3 \times 6$mm brass heat set inset on the bottom to interface with the top and bottom braces receptively. The side brace also has a feature to interface with the bottom set of $\diameter 3$mm Carbon Fiber Rods. The part is designed for the left and is mirrored to fit for the right side. The part is printed with the top surface facing down, at a layer height of $0.2$mm, has $3$ perimeters and a $25\%$ infill.

\begin{figure}[H]
    \centering
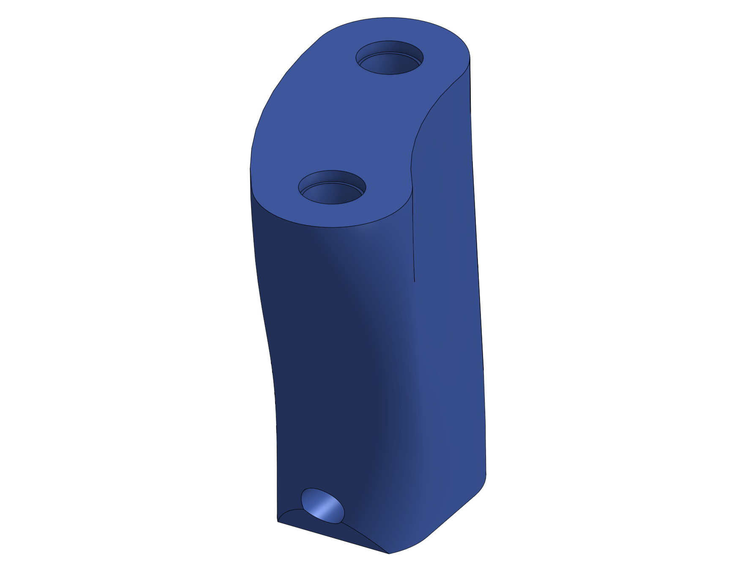
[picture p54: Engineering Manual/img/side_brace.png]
    
    \caption{The Side Brace.}
    \label{fig:C_SC_SB} 
\end{figure}

They all combine to form the steering column.

\subsubsection*{Servo Horn}

The servo horn is the part that clamps on the the shaft of thew servo and interfaces with the steering linkage rods. It is a fairly simple part. It houses a $\diameter 6$mm  hole at one end and the space for a M$3 \times 6$ spacer (See Figure \ref{fig:C_SH}, grey) that is press fit into it. The distance between the two is $30$mm. The height of the part is also $6$mm. The part is printed at a layer height of $0.2$mm, has $3$ perimeters and a $25\%$ infill. To maximize the frictional force, the inside surface of the hole is printed with Fuzzy Skin, with a thickness of $0.1$mm and $0.2$mm.

\begin{figure}[H]
    \centering
    
    \caption{The Servo Horn.}
    \label{fig:C_SH} 
\end{figure}

\subsubsection*{Steering Links}

The steering links, along with a $\diameter 3$mm Carbon Fiber rod make up the steering rod. The links have $2$ parts (See Figure \ref{fig:C_SL}), one that connects to the servo, the servo link (Figure \ref{fig:C_SL_Servo}) and the other other that connects to the knuckle (Figure \ref{fig:C_SL_Wheel}), the wheel link. The servo link has a height of $7.1$mm with a $\diameter 3$mm hole running through the center for a M$3 \times 10$mm screw. It also has a space for the carbon fiber rod perpendicular to the screw. The wheel link is similar with a height of $5$mm and a hole for a M$2 \times 20$mm screw that connects it to the steering knuckles. The two links rely on the screw as a "pin" to rotate freely. A bearing is not used for this revolute joint as the size is too small to accommodate any and the force are low. The part is printed at a layer height of $0.12$mm, has $3$ perimeters and a solid infill. $2$ sets of these are needed to form the $2$ steering rods. One is mounted at the top and the other at the bottom (Figure \ref{fig:C_SL_Context}).

\begin{figure}[H]
    \centering
    % --- Left Column (Stacked Images) ---
    \begin{subfigure}[b]{0.45\textwidth}
        \centering
        \begin{subfigure}[b]{\textwidth}
            \centering
            
            \caption{Servo Link}
            \label{fig:C_SL_Servo}
        \end{subfigure}
        
        \vspace{1.5em} % Balanced spacing between the two stacked images
        
        \begin{subfigure}[b]{\textwidth}
            \centering
            
            \caption{Wheel Link}
            \label{fig:C_SL_Wheel}
        \end{subfigure}
    \end{subfigure}
    \hfill
    % --- Right Column (Vertical Image Aligned to Center) ---
    \begin{subfigure}[b]{0.48\textwidth}
        \centering
        % Using \linewidth ensures it fits cleanly within its column boundary
        
        \caption{Installation Context}
        \label{fig:C_SL_Context}
    \end{subfigure}

    \caption{The Steering Links}
    \label{fig:C_SL}
\end{figure}

\subsubsection*{TPU Spacer/Shim}

A Outer $\diameter 16$mm and inner $\diameter 12.80$mm spacer, with a height of $6$mm is needed. This sits between the bearing and the wheel and provides pre-load to the whole stack up. This is used as the roller thrust bearing is only constrained in one direction by the end cap. The other end is hence constrained by the TPU spacer and the pre-load it provides. The pre-load also ensures there is as little play between the axle and the bearing as possible. Figure \ref{fig:C_TPUS} (red) shows the placement of the spacer in section view. Since it is made out of a flexible material with a shore hardness of $95$A, the height of the spacer determines the pre-load force. The part is printed at a layer height of $0.2$mm, has $3$ perimeters and a solid infill. It is utilized on both sides.

\begin{figure}[H]
    \centering
    
    \caption{The TPU Spacer.}
    \label{fig:C_TPUS} 
\end{figure}

This concludes the assembly of the front axle. The length of the $\diameter 3$mm carbon fiber rod used in the steering links is $\approx 48$mm. It is glued to the steering links. 

\subsection{The Differential}

\begin{figure}[H]
    \centering
    
    \caption{The Differential Gearbox.}
    \label{fig:C_DG_Assem} 
\end{figure}

As mentioned earlier, a differential gear box is used. The center of the gearbox is formed by the "spider" gears and the carrier along with the main gearbox. In a differential gearbox, the housing containing the spider and main gears also rotates and is mounted to a stationary mount. The housing contains the main gear reduction for the differential. The spider gears assist with the difference in speeds of the two main gears (and hence wheels). All of the parts of the gearbox are 3D printed. The net reduction produced is $8:28 = 2:7$.

\subsubsection*{The Gears}

The differential consists of $3$ spider gears and $2$ main gears All the gears present are bevel gears created using the OnShape bevel gear scripts. \\

The spider gears have $9$ teeth, a module of $1.5$mm, a pressure angle of $20^{\circ}$ and a bevel angle of $30.96^{\circ}$. The spider gears have a $\diameter 3$mm hole through the center to interface with the axle. The top has be flattened to aid with printing. They are set $120^{\circ}$ apart. See Figure \ref{fig:C_DG_SG}. \\

The main gears have $15$ teeth, a module of $1.5$mm, a pressure angle of $20^{\circ}$ and a bevel angle of $59.04^{\circ}$. Notice that the bevel angles of the 2 types add up to $90^{\circ}$. The main gear transfer all the load to the wheels. Hence, using a single screw in the center would cause it to loosen due to the torque caused. Hence, $2$ screws are use that are placed $3$mm apart from the center to connect the gears to the part that interfaces with the rear axles. Behind the gear sits a $\diameter 12$mm $\times 11$mm cylinder that interfaces with the bearings. The top has be flattened to aid with printing. See Figure \ref{fig:C_DG_MG}.

\begin{figure}[H]
    \centering
    % --- Left Column (Stacked Images) ---
    \begin{subfigure}[b]{0.45\textwidth}
        \centering
        \begin{subfigure}[b]{\textwidth}
            \centering
            
            \caption{The Spider Gear}
            \label{fig:C_DG_SG}
        \end{subfigure}
        
        \vspace{1.5em} % Balanced spacing between the two stacked images
        
        \begin{subfigure}[b]{\textwidth}
            \centering
            
            \caption{The Main Gear}
            \label{fig:C_DG_MG}
        \end{subfigure}
    \end{subfigure}
    \hfill
    % --- Right Column (Vertical Image Aligned to Center) ---
    \begin{subfigure}[b]{0.48\textwidth}
        \centering
        % Using \linewidth ensures it fits cleanly within its column boundary
        
        \caption{Installation Context}
        \label{fig:C_DG_Context}
    \end{subfigure}
    \caption{The Differential Gears}
    \label{fig:C_DG}
\end{figure}

All 5 of the parts are printed at a layer height of $0.12$mm, has $3$ perimeters and a solid infill. A brim is used to aid with bed adhesion. The spider gears and the main gears are printed with the gear face facing down. This means that the forces of the gears runs along the layer. However, this means that the rotational force of the main gear to the wheels runs across the layer lines, which would mean that the are where the gear ends and the cylinder starts is the weakest area. To counter this, the M$3 \times 20$ button head screws that are used to connect the main gear and the axles run all the way to the end of the gear, meaning they transfer most of the rotational loads and strengthen the part's function across the layer lines. See figure \ref{fig:C_DG_Context}.

\subsubsection*{The Carrier/Spider Center}

The Spider Center is the part that holds all the spider hears in the center and aligns them. In the housing, it is suspended by the M$3 \times 10$mm Button Head screws. See Figure \ref{fig:C_DG_SC}. \\

It's a filleted triangle with 3 $\diameter 3$mm holes on each side. It has a height of $6$mm. It is printed at a layer height of $0.12$mm, has $3$ perimeters and a solid infill. A brim is used to aid with bed adhesion. The part can be printed on either of the larger, flat surfaces.

\begin{figure}[H]
    \centering
    \begin{subfigure}[b]{0.48\textwidth}
        \centering
        
        \caption{The Part.}
        \label{fig:diff_sc_1}
    \end{subfigure}
    \hfill
    \begin{subfigure}[b]{0.48\textwidth}
        \centering
        
        \caption{The Spider Center in Action.}
        \label{fig:diff_sc_2}
    \end{subfigure}
    
    \caption{The Spider Center.}
    \label{fig:C_DG_SC}
\end{figure}

\subsubsection*{Housing}

The housing for the differential gears consists of $2$ halves, the left half and the right half. The two halves are connected by $3$ M$3 \times 30$mm screws and M$3$ nuts (See Figure \ref{fig:C_DG_Assem}). \\

The housing not only houses the gears but also $2 \times$ 6901ZZ bearings (Figure \ref{fig:roller_bearing}). This is to decouple the rotation of the main gears with the rotation of the housing when the two axles are spinning at different speeds. The left housing and the right housing are nearly identical. The left housing houses the bevel gear ring needed to rotate the differential housing using the motor. That gear has $28$ teeth, a module of $1.5$mm and a bevel angle of $70^{\circ}$. In Figure \ref{fig:C_DG_H}, the left housing is the one in light blue and the right housing is in dark blue. The bearings sit inside the housing. \\

The part is printed with the center surface of each of the half facing down. Looking carefully, a chamfer is  present on the end where the bearings sit. This allows for the overhangs to be managed better. It is printed at a layer height of $0.12$mm, has $3$ perimeters and a $25\%$ infill. A brim is used to aid with bed adhesion. 

\begin{figure}[H]
    \centering
    
    \caption{The Housing for the Gearbox.}
    \label{fig:C_DG_H} 
\end{figure}

\subsubsection*{The Attaching Cups}

The Cup is the part that interfaces with main gear and the $\diameter 12$mm carbon fiber tube that serves as the rear axle. It has the same mounting patter as the Main gear ($6$mm spacing between the 2 M$3$ screws). The Cup extends the $12$mm cylinder outward to house the $12$mm rod. It also has $2 \times \diameter 2$mm holes at each end to interface with the axle and transfer the load. \\

For printing, the cup is split into 2 parts axially (see Figure \ref{fig:C_DG_C}) and then printed flat to ensure the force moves along the layers and ensure ease of printability. It is printed at a layer height of $0.12$mm, has $3$ perimeters and a $25\%$ infill. A brim is used to aid with bed adhesion. 

\begin{figure}[H]
    \centering
    
    \caption{The Attaching Cup.}
    \label{fig:C_DG_C} 
\end{figure}

\subsubsection*{The Spacer}

When looking at Figure \ref{fig:C_DG_Assem}, one can see that there are bearings on the outside as well, excluding the ones inside the housing. These are also 6901ZZ bearings and are responsible for the rotation of the housing itself. They are clamped from either end (discussed later). To ensure that there is $\rightarrow$
\begin{enumerate}
\item No play in the mounting of the differential gearbox
\item Adequate separation between the bearing ends and the housing of the wall
\item Ease of motion
\end{enumerate}
A spacer disk is mounted in between the two bearings. This disk also provides the pre-load needed in the gearbox stackup. It also ensures that the main gears in the differential mesh properly with the spider gears. Unlike the TPU spacer (Figure \ref{fig:C_TPUS}), this is made out of PLA. \\

It is printed at a layer height of $0.12$mm, has $3$ perimeters and a $25\%$ infill. A brim is used to aid with bed adhesion. The height of the disk, nominally $2.00$mm can be adjusted to adjust the pre-load. The grove of the roller bearing (Figure \ref{fig:roller_bearing}). The disk has an outer diameter of $16.40$mm and an inner diameter of $12.4$mm. You can see the orange disk in Figure \ref{fig:C_DG_Spacer} doing its job.

\begin{figure}[H]
    \centering
    
    \caption{The Spacer Disk.}
    \label{fig:C_DG_Spacer} 
\end{figure}

\subsection{The Rear Axle}

The rear axle is what really brings everything together. The mounts for the rear axle hold the motor, the batteries, the needle roller bearings and the differential. They are also the end point of the 4 carbon fiber rods used to strengthen the vehicle. The parts for the rear axle are also among the largest parts. \\

The rear axle houses the 2 BCWN-T-d12-IR bearings (Figure \ref{fig:needle_roller_bearing}). We start our journey with the Rear Axle Mount. It encompasses the whole rear axle and only consists of 2 parts that work in tandem.

\begin{figure}[H]
    \centering
    
    \caption{The Rear Axle Assembly.}
    \label{fig:C_R_Assem} 
\end{figure}

\subsubsection*{Rear Axle Mount Front}

The front mount is the light blue colored part in Figure \ref{fig:C_R_Assem}. It houses the motor and serves as one half of the gearbox mount. It is one of the most complex parts. \\

It houses holes for $6$ M$3 \times 8$mm screws that connect the motor to the mount. It also has space for $4$ M$3 \times 4$mm heat set inserts at the very end to interface with the back mount and space for $6$ M$3 \times 6$mm heat set inserts, $3$ on each side (see Figure \ref{fig:C_R_FM}) that allow it to interface with the parts that connect the front and the rear axle. The front mount also serves as the end point of the bottom set of $\diameter 3$mm rods. \\

The part is printed with the forward facing face in Figure \ref{fig:C_R_Assem} pointing down, as shown in Figure \ref{fig:C_R_FM_P}. The part does need supports at the area where the motor mounts. It is printed at a layer height of $0.20$mm, has $3$ perimeters and a $25\%$ infill. A brim is used to aid with bed adhesion.

\begin{figure}[H]
    \centering
    
    \caption{The Front Mount.}
    \label{fig:C_R_FM} 
\end{figure}

\begin{figure}[H]
    \centering
    
    \caption{The Front Mount in the Slicer.}
    \label{fig:C_R_FM_P} 
\end{figure}

\subsubsection*{Rear Axle Mount Rear}

The rear mount serves as a half to mount the BCWN-T-d12-IR as well as the 6901ZZ bearings. It's a fairly chunky piece. It uses 8 M$3 \times 8$mm screws that interface with the rest of the vehicle. This part serves as the end mount of the top $\diameter 3$mm carbon fiber rods. \\

The part prints with the front face facing downward. It is printed at a layer height of $0.20$mm, has $3$ perimeters and a $25\%$ infill. A brim is used to aid with bed adhesion and prevent warping. Supports are not needed but appreciated. \\

\begin{figure}[H]
    \centering
    
    \caption{The Back Mount.}
    \label{fig:C_R_BM} 
\end{figure}

The batteries mount above the rear axle and are shown in the next section.

\subsection{The Center}

This part ties the the two axles together. It houses the LiDAR, the Raspberry Pi, the ESC and the batteries. 

\begin{figure}[H]
    \centering
    
    \caption{The Center Assembly.}
    \label{fig:C_C_Assem} 
\end{figure}

\subsubsection*{Top Brace}

The top brace is the main part that connects the motor mount to the steering column. The top supporting rods run directly, all the way through this. It is one of the two biggest parts of the entire vehicle. \\

It connects to the motor mount (Rear axle mount front) with $6$ M$3 \time 16$mm screws and connects with the steering mount with $2$ M$3 \times 12$mm screws. It takes $2$ M$3 \times 6$m heat set inserts on the top surface for the LiDAR \& ESC mount. \\

The part is printed with the rear facing surface pointing downward (the part is upright) and does not require any supports. The holes at the front in Figure \ref{fig:C_C_Top} are counter bore, but features are provided to help with printing. PreFlight can also be used to aid with counter bore bridging.

\begin{figure}[H]
    \centering
    
    \caption{The Top Brace.}
    \label{fig:C_C_Top} 
\end{figure}

The part is printed at a layer height of $0.20$mm, has $3$ perimeters and a $25\%$ infill. A brim is used to aid with bed adhesion and prevent the part from peeling off when printing.

\subsubsection*{Bottom Left \& Bottom Right Brace}

The bottom left and bottom right braces are just mirrored parts. They are tiny in comparison to the top brace. They help with connecting the top brace to the bottom pair of carbon fiber rods. They also interface with the motor mount (Rear axle mount front) on the same $6$ points as the top brace. They are wedged between the motor mount and the top brace. \\

They are printed with either of the end, flat, sides pointing down. They do not need supports and are printed at a layer height of $0.20$mm, has $3$ perimeters and a $25\%$ infill. A brim is used to aid with bed adhesion and prevent the part from peeling off when printing.

\begin{figure}[H]
    \centering
    
    \caption{The Bottom Left and Right Brace.}
    \label{fig:C_C_Bot} 
\end{figure}

\subsubsection*{Rear Bearing Mounts}

\begin{figure}[H]
    \centering
    
    \caption{The Left and Right Bearing mounts.}
    \label{fig:C_C_Back} 
\end{figure}

These parts go on the outside of the motor mount and top brace sandwich. They serve 2 purposes, one of them is holding the BCWN-T-d12-IR bearing and the other is holding the batteries. The battery straps go though this part. Each one of them is more or less a mirror but the right one has a larger loft for no apparent reason. \\

They are printed with the bottom side facing down. They do not need supports and are printed at a layer height of $0.20$mm, has $3$ perimeters and a $25\%$ infill. A brim is used to aid with bed adhesion and prevent the part from peeling off when printing.

\subsubsection*{LiDAR \& ESC mount}

The LiDAR and ESC mount is one of the two largest parts on the entire vehicle. They mount spans almost the entire breadth of the vehicle. It mouns the ESC on one side, screws into the top brace, mounts the LiDAR and connects to one of the bottom screw holes of the Raspberry Pi. \\

The part has holes to reduce its weight and a recess in on the top to accommodate for the LiDAR's electronics. The ESC has its fan removed and the screws from the shroud are used to mount. There are $3$ M$3 \times 6$mm heat set inserts to mount the LiDAR. The LiDAR uses $3$ M$3 \times 10$ countersunk screws. The mount prints on the face where the ESC mounts from. The part doesn't not need supports, but they are appreciated. It is printed at a layer height of $0.20$mm, has $3$ perimeters and a $25\%$ infill. A brim is used to aid with bed adhesion and prevent the part from peeling off when printing.

\begin{figure}[H]
   \centering
   
   \caption{The Lidar \& ESC mount.}
   \label{fig:C_C_LM} 
\end{figure}

\subsection{Accessories}

There are several parts that don't fall into a single category but are essential or quality of life improvements.

\subsubsection*{Wheel Hub}
\label{Wheel Hub}
The wheel hub is the part that goes around the custom silicone casting as discussed earlier. It has to grip the cast tire and attach to the axles securely. To do this, it uses a single M$2 \times 12$mm screw. The wheel hub is  a tight interference fit with both the wheel and the axle. It is $18$mm wide, same as the cast tire. \\

The wheel hub is printed at a layer height of $0.20$mm has $3$ perimeters and a $25\%$ infill. A brim is used to aid with bed adhesion and prevent the part from peeling off when printing. The outer surface (where the wheel hub and tire touch), see Figure \ref{fig:C_W_H}, has a fuzzy skin, with a thickness of $0.1$mm and $0.2$mm. \\

\begin{figure}[H]
   \centering
   
   \caption{The Wheel Hub.}
   \label{fig:C_W_H} 
\end{figure}

\subsubsection*{Raspberry Pi Mount}

This part holds the raspberry pi by the forward $2$ mounting holes and constrains it via attaching it to the bottom $2$ carbon fiber brace rods. The part is fairly simple. It interfaces with the $\diameter 3$mm rods via holes and interfaces with the pi with $2$ M$2.5 \times 8$mm screws. \\

The part is printed with any of the large, flat faces (see Figure \ref{fig:C_A_RPM}) facing down and does not need supports. It is printed at a layer height of $0.20$mm, has $3$ perimeters and a $25\%$ infill. \\

\begin{figure}[H]
   \centering
   
   \caption{The Raspberry Pi Mount.}
   \label{fig:C_A_RPM} 
\end{figure}

\subsubsection*{ESC Wire Mount}

This is a very simple part that attaches with the bottom right brace rod and uses zip-ties to helpd the motor and ESC wires in a neat bundle. It's only $2$mm think and serves the purpose. The part is printed with any of the large, flat faces (see Figure \ref{fig:C_A_Wmount}) facing down and does not need supports. It is printed at a layer height of $0.20$mm, has $3$ perimeters and a $25\%$ infill.

\begin{figure}[H]
   \centering
   
   \caption{The ESC Wire Mount.}
   \label{fig:C_A_Wmount} 
\end{figure}

\subsection{Tools}

There were several tools used for cutting, drilling and casting. These tools don't make it to the final vehicle but are an integral part of the buld process.

\subsubsection*{Tire Molds}

The mold for the tire, as mentioned earlier, is printed in Resin via the SLA manufacturing process. It is a two part mold that clamps via $4$ M$3 \times 30$mm screws and M$3$ nuts. It is advised to add washers to both sides. The mold does not have any draft angles as it was intended to be resin printed where the layer lines are microscopic and can be filled in by mold release. The mold can be FDM printed but would need draft angles. \\

It is a simple $2$ par mold that has the negatives for the tire. The top and bottom are more or less mirrors of each other with the only difference being that the top has an entry and exit hole to help with the pouring process. \\

\begin{figure}[H]
   \centering
   
   \caption{The Mold for the Polyurethane Tire.}
   \label{fig:C_W_Mold} 
\end{figure}

\subsubsection*{Standoff Cutting}

To attach the Raspberry Pi to the custom hat, $15$mm nylon female to female standoffs are used. However, the actual spacing comes out to be $14$mm. For a better fit, we decided to cut the standoffs to length, \textbf{however, this is completely optional}. To do this, a simple tool was made. \\

The part has the space for the standoff where it is pressed against a wall. It has a slit for a razor blade that allows it to slot in and cut straight and at length. The part is printed upright, as depicted in Figure \ref{fig:C_T_SC}. It is printed at a layer height of $0.20$mm, has $3$ perimeters and a $25\%$ infill.

\begin{figure}[H]
   \centering
   
   \caption{The Standoff Cutting Tool.}
   \label{fig:C_T_SC} 
\end{figure}

\subsubsection*{Axle Cutting}

\textbf{Caution:} \textit{Carbon Fiber dust is not very nice to inhale, all carbon fiber related tasks that involve manufacturing should be done with the part submerged in water to prevent the dust getting in the air and in a well ventilated area with a respirator and eye protection.} \\

The rear axle consists of $2$ $\diameter 12 \times 60$mm Carbon fiber tubes. The tube sourced was $500$mm in length. To cut it down to length, a tool was needed. \\

The part takes in the carbon fiber tube until it is pressed against an inner wall. It has a slit for the saw blade. It is printed upright, as depicted in Figure \ref{fig:C_T_RC}. It is printed at a layer height of $0.20$mm, has $3$ perimeters and a $25\%$ infill.

\begin{figure}[H]
   \centering
   
   \caption{The Axle Cutting Tool.}
   \label{fig:C_T_RC} 
\end{figure}

\subsubsection*{Axle Drilling}

\textbf{Caution:} \textit{Carbon Fiber dust is not very nice to inhale, all carbon fiber related tasks that involve manufacturing should be done with the part submerged in water to prevent the dust getting in the air and in a well ventilated area with a respirator and eye protection.} \\

The rear axle interfaces with the other parts via M$2$ screws. This means that it needs a $\diameter 2$mm hole at each end. This hole is spaced $4.5$mm from each edge. To do this, a tool was needed. \\

The tool has a hole for a $2$mm High Speed Steel or Carbide Drill Bit and a hole for the tube to slot in till it hits an internal wall. It is printed with the back face, the only face without any features or fillets, pointing down (see Figure \ref{fig:C_T_RD}). It is printed at a layer height of $0.20$mm, has $3$ perimeters and a $25\%$ infill.

\begin{figure}[H]
   \centering
   
   \caption{The Axle Drilling Tool.}
   \label{fig:C_T_RD} 
\end{figure}

\subsection{Notes}

All the parts are printed in PLA till mentioned otherwise.\\

The nominal settings are using the arachne wall engine with 3 bottom layers and 4 top layers with Gyroid infill. The nominal perimeter width is $0.4$mm. One may need some post processing if not using a well calibrated printer. Some parts intentionally do not have clearances to interact better. \\

All the $3$D files can be found in the "/models" directory, organized into sub sections. The files are in the ".STEP" format, allowing others to modify and change the files. The files are published under the GNU Affero General Public License (AGPL), meaning all changed files need to be published as well. \\

Thanks again to the Orca Slicer and the PreFlight Slicer teams for the amazing and open source software they provide. \\

\textbf{The BOM for the screws is available in the "other" as well as "models" folder.}

\pagebreak

\section{OS and Configurations}

The Raspberry Pi uses a $64$GB SD card. It is flashed with Ubuntu 22.04.5 Server. This is used with ROS 2 Humble Hawksbill. What is ROS and why use it?\\

ROS (Robot Operating System) is an open-source robotics middleware framework. Rather than a traditional operating system like Linux or Windows, ROS acts as a communication backbone. It connects the main compute board (e.g., Raspberry Pi) to your sensors (LiDAR, camera, IMU) and motor controllers, allowing different software modules to send data to each other seamlessly. \\

\textbf{Reasons to use ROS}
\begin{enumerate}
\item \textbf{Process Decoupling}: Runs perception, navigation, and motor control as separate, independent nodes. A crash or lag in image processing won't freeze the real-time steering/drive loop.
\item \textbf{Automated Frame Transformations (tf2)}: Computes precise spatial math and coordinate transforms between different physical points on the car (e.g., center of mass $\rightarrow$ LiDAR offset $\rightarrow$ camera offset).
\item \textbf{Sensor Synchronization}: Provides built-in tools (message filters) to align high-bandwidth feeds (camera frames and 2D LiDAR scans) with low-level IMU and encoder data.
\item \textbf{Data Logging \& Offline Replay (rosbag)}: Records full track run data to replay offline, letting you refine algorithms and tune controllers without physical track time or draining LiPo batteries.
\item \textbf{Live Visualization (RViz)}: Displays real-time 2D LiDAR sweeps, camera overlays, and projected path trajectories live on screen during testing.
\item \textbf{WRO Rubric Alignment}: Fulfills competition evaluation criteria for software modularity, state-machine design, and code reproducibility required in the engineering journal and GitHub repository (refer to README.md).
\end{enumerate}

Hence ROS was used. Why Humble Hawksbill? Because it was the latest stable release at the time of starting this. \\

\subsection{Camera ROS 2 Integration}

Ubuntu has a lot of driver issues, especially when running it on an SBC like a Raspberry Pi. They are annoying but navigable.

\subsubsection*{Driver Constraints \& Hardware Sensor Binning}
Configuring the Arducam IMX219 ($175^\circ$ FOV) on Ubuntu 22.04 LTS (64-bit) requires modern \texttt{libcamera} overlays rather than legacy MMAL drivers. To maintain the full field-of-view without cropping or high CPU overhead, the sensor's native \textbf{hardware binning (subsampling)} mode is utilized. This mode samples the entire $3280 \times 2464$ sensor plane but combines pixels on-chip down to $640 \times 480$, preserving the full $175^\circ$ FOV while drastically reducing transport latency for real-time ROS 2 inference.

\subsubsection*{Configuration \& Node Execution}
Configure the sensor overlay in \texttt{/boot/firmware/config.txt} (\texttt{start\_x=1}, \texttt{gpu\_mem=128}, \texttt{dtoverlay=imx219}) and reboot. 

After installing \texttt{ros-humble-camera-ros}, launch the camera node in binned $640 \times 480$ \texttt{RGB888} format to publish to  image/raw:
\begin{verbatim}
ros2 run camera_ros camera_node --ros-args \
  -p format:="RGB888" -p width:=640 -p height:=480
\end{verbatim}

\subsection{Hardware PWM Configuration \& Tuning}

\subsubsection*{Pinout \& Driver Setup}
Dual-channel hardware PWM on the Raspberry Pi 4B utilizes PWM0 (GPIO 12 / Pin 32) and PWM1 (GPIO 13 / Pin 33) operating at 50~Hz ($20\,\text{ms}$ period). Because the PWM hardware clock controller shares resources with onboard audio, audio must be disabled in firmware and blacklisted in the kernel:

\begin{enumerate}
    \item \textbf{Firmware Overlay:} Add \texttt{dtoverlay=pwm-2chan,pin=12,func=4,pin2=13,func2=4} and \texttt{dtparam=audio=off} to \texttt{/boot/firmware/config.txt}.
    \item \textbf{Kernel Blacklisting:} Blacklist the audio module by adding \texttt{blacklist snd\_bcm2835} to \texttt{/etc/modprobe.d/raspi-blacklist.conf}.
\end{enumerate}

\subsubsection*{Servo Pulse Limits \& Power Stability}
The S2500M steering servo is calibrated at 50~Hz with strict pulse boundaries:
\begin{itemize}
    \item \textbf{Pulse Boundaries:} Neutral at $1500\,\mu\text{s}$, minimum safe pulse at $700\,\mu\text{s}$ ($\approx 0^\circ$), and maximum safe pulse at $2300\,\mu\text{s}$ ($\approx 180^\circ$).
    \item \textbf{Thermal/Current Throttling:} Exceeding $2300\,\mu\text{s}$ forces the servo against mechanical hard stops, triggering internal thermal throttling with 5-second recovery delays.
    \item \textbf{Power Integrity:} Requires a common ground path across the Pi, HAT, and power rail, along with a $470\,\mu\text{F}$ decoupling capacitor across 5V/GND to absorb inrush spikes.
\end{itemize}

\subsubsection*{Linux Sysfs Execution Sequence}
When interfacing via \texttt{/sys/class/pwm/pwmchip0/}, write sysfs parameters in strict order:
\begin{enumerate}
    \item Disable output (\texttt{enable = 0}).
    \item Set period first (\texttt{period = 20000000}).
    \item Set pulse width second (\texttt{duty\_cycle = 1500000}).
    \item Enable output (\texttt{enable = 1}).
\end{enumerate}

\pagebreak

\section{Control Architecture \& Software System}

\subsection{System Architecture \& ROS 2 Pipeline}
The software stack is structured as a modular ROS 2 architecture comprising three primary subsystems: Perception, Decision \& Control, and Mobility/Actuation. Inter-node communication relies on standard ROS 2 topics to maintain real-time responsiveness.

\begin{figure}[h!]
\centering
\begin{tikzpicture}[
    node distance = 1.2cm and 1.5cm,
    sensor/.style = {rectangle, draw, rounded corners=3pt, fill=orange!10, thick, align=center, inner sep=6pt, font=\small},
    nodeblock/.style = {rectangle, draw, rounded corners=4pt, fill=blue!5, thick, align=left, inner sep=8pt, font=\small},
    arrow/.style = {-{Stealth[length=2.5mm]}, thick},
    topicalign/.style = {font=\footnotesize\ttfamily, fill=white, inner sep=2pt}
]

    % Sensor Nodes
    \node (lidar) [sensor] {\textbf{YD-LiDAR X4 Pro}\\(15\,Hz)};
    \node (camera) [sensor, right=2.0cm of lidar] {\textbf{Arducam IMX219}\\($175^\circ$\,FOV)};

    % Decision / Control Node
    \node (control) [nodeblock, below=1.5cm of $(lidar.south)!0.5!(camera.south)$, anchor=north] {
        \textbf{\large /control Node}\\[4pt]
        \begin{minipage}{9.2cm}
        \begin{itemize}[leftmargin=12pt, itemsep=1pt, topsep=2pt]
            \item RANSAC Wall Line Extraction \& Heading Offset Calculation
            \item Pillar Clustering \& Camera ROI Color Query
            \item Dynamic Velocity \& Braking Distance Calculation
            \item State Machine Logic \& Lap/Turn Counter
            \item RViz Marker Publisher (\texttt{/visualization\_marker})
        \end{itemize}
        \end{minipage}
    };

    % Mobility / Actuation Node
    \node (mobility) [nodeblock, below=1.8cm of control.south, anchor=north] {
        \textbf{\large /mobility Node}\\[4pt]
        \begin{minipage}{9.2cm}
        \begin{itemize}[leftmargin=12pt, itemsep=1pt, topsep=2pt]
            \item Hardware PWM Driver (\texttt{/sys/class/pwm})
            \item Servo Pulse Boundary Mapping ($700\,\mu\text{s}$ -- $2300\,\mu\text{s}$)
            \item Motor Throttle Duty Cycle Mapping ($-100$ to $+100$)
        \end{itemize}
        \end{minipage}
    };

    % Sensor Dataflow Arrows
    \draw [arrow] (lidar.south) -- (lidar.south |- control.north) 
        node[midway, topicalign] {/scan};
    \draw [arrow] (camera.south) -- (camera.south |- control.north) 
        node[midway, topicalign] {/image\_raw};

    % Mobility Control Arrows
    \draw [arrow] ($(control.south)!0.3!(control.south west)$) -- ($(mobility.north)!0.3!(mobility.north west)$) 
        node[midway, topicalign] {/throttle};
    \draw [arrow] ($(control.south)!0.3!(control.south east)$) -- ($(mobility.north)!0.3!(mobility.north east)$) 
        node[midway, topicalign] {/steer};

\end{tikzpicture}
\caption{ROS 2 System Control Architecture and Inter-Node Dataflow Diagram.}
\label{fig:control_architecture}
\end{figure}

\subsection{ROS 2 Topics \& Interfaces}
\begin{itemize}
    \item \textbf{\texttt{/scan} Topic (\texttt{sensor\_msgs/msg/LaserScan}):} Published by the LiDAR node at a nominal frequency of $15\,\text{Hz}$, containing 2D range arrays over $360^\circ$.
    \item \textbf{\texttt{/steer} Topic (\texttt{std\_msgs/msg/Float32}):} Published by the \texttt{/control} node to command target Ackermann steering angles. The \texttt{/mobility} node maps these commands to PWM duty cycles ($700\,\mu\text{s}$ to $2300\,\mu\text{s}$) on GPIO 12.
    \item \textbf{\texttt{/throttle} Topic (\texttt{std\_msgs/msg/Int8}):} Published by the \texttt{/control} node to set motor velocity demands from $-100$ (full braking / reverse) to $+100$ (maximum forward acceleration), with $0$ representing neutral.
    \item \textbf{\texttt{/visualization\_marker} Topic (\texttt{visualization\_msgs/msg/Marker}):} Streams 3D geometric markers to RViz to display vehicle position, extracted wall vectors, and mapped pillar locations.
\end{itemize}

\subsection{Perception Algorithms \& Path Extraction}

\subsubsection{RANSAC Wall Extraction \& Heading Offset}
2D range arrays from \texttt{/scan} within the perception radius are processed using a Random Sample Consensus (RANSAC) line-fitting algorithm to extract straight wall vectors. The controller calculates the lateral offset error $e_d$ and heading angular error $\theta$ relative to the wall vector to derive the Ackermann steering command $\delta$:
\begin{equation}
\delta = K_p \cdot \theta + K_d \cdot e_d
\end{equation}
where $K_p$ and $K_d$ represent proportional and derivative control gains.

\subsubsection{Dynamic Velocity-Dependent Braking}
To prevent cornering overshoot, the braking initiation distance $d_{\text{brake}}$ is calculated dynamically as a function of current vehicle velocity $v$:
\begin{equation}
d_{\text{brake}} = d_{\text{min}} + k_v \cdot v^2
\end{equation}
where $d_{\text{min}}$ is the baseline stopping distance and $k_v$ is an empirical braking coefficient.

\subsection{Challenge Execution Logic}

\subsubsection{Round One: Obstacle-Free Wall Following}
\paragraph{Startup Sequence:} Pressing the hardware start switch initiates a non-blocking startup delay. This allows the LiDAR motor to reach nominal operating speed ($15\,\text{Hz}$) and ensures team members clear the operational area.

\paragraph{Wall-Following \& Turn Management:} The \texttt{/control} node evaluates wall vectors to execute directional turns, adjusts dynamic velocity/braking thresholds, and tracks completed turns and laps.

\subsubsection{Round Two: Pillar Mapping \& Parallel Parking}
\paragraph{Exit Maneuver \& Direction Initialization:} Operation begins with an automated exit sequence from the parallel parking bay, after which the primary circuit direction is established.

\paragraph{Pillar Clustering \& Camera Color Fusion:} The \texttt{/control} node clusters contiguous points in \texttt{/scan} data to detect cylindrical pillars, computing their range and bearing angle $\phi$. The node queries the wide-angle camera for average color values (RGB/HSV) within the Region of Interest (ROI) corresponding to bearing $\phi$. The identified color (Red/Green) is logged on the occupancy map to dictate navigation paths (e.g., passing Red pillars on the right, Green on the left).

\paragraph{Automated Parallel Parking Finalization:} Upon completing the pillar circuit, the vehicle transitions into parallel parking mode, utilizing lateral wall range measurements to execute a multi-point alignment into the parking bay.

\pagebreak

\section{Conclusion \& Acknowledgments}

Building our autonomous vehicle for the WRO Future Engineers challenge has been an invaluable journey of iterative design, engineering trade-offs, and practical problem-solving. From casting custom $40\text{A}$ polyurethane tires and designing a 4-layer PCB hat to configuring ROS 2 nodes and tuning hardware PWM timings, every sub-assembly represents hands-on learning and technical growth.

\subsection{Document Production}
This manual and technical documentation suite were authored using \LaTeX{} and compiled using \textbf{TeXmaker}. In the spirit of open collaboration, all CAD STEP models, schematics, and hardware BOMs are published under the GNU Affero General Public License (AGPLv3) for the robotics community.

\subsection{Open-Source Acknowledgments}
This project relies heavily on the open-source ecosystem and accessible software platforms. We express our gratitude to the developers, maintainers, and communities behind the following tools:

\begin{itemize}
    \item \textbf{TeXmaker \& \LaTeX{}:} For providing a reliable typesetting environment for technical manual generation.
    \item \textbf{KiCAD:} For enabling 4-layer PCB schematic capture, routing, and 3D visualization.
    \item \textbf{Orca Slicer \& PreFlight Slicer:} For advanced toolpath generation, Arachne wall engines, and precise 3D printing execution.
    \item \textbf{ROS 2 (Humble Hawksbill):} For supplying a robust middleware framework for robotics perception and node communication.
    \item \textbf{Onshape:} For flexible 3D CAD modeling and parametric assembly management.
    \item \textbf{Interactive HTML BOM:} For generating interactive assembly guides for surface-mount soldering.
    \item \textbf{Linux \& Raspberry Pi Community:} For maintaining the embedded drivers, overlays, and hardware documentation.
\end{itemize}

Thank you to the WRO organizers, judges, fellow competitors, and the broader open-source community for making this journey possible.

\end{document}

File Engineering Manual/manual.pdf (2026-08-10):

# WRO Engineering Manual

### Team: The Redacted

### August 10, 2026

## Contents

1 Selection of Components | 5
2 PCB Assembly | 15
3 3D Prints & CAD | 29

## List of Figures

1 | The YD-LiDAR X4 Pro | | 6
2 | The IMX219 with a very wide angle lens | | 6
3 | The Raspberry Pi 4 Model B | | 7
4 | The Motor | | 8
5 | The ESC | | 9
6 | The Configuration Device that connects via PWM | | 9
7 | The S2500M metal gear servo motor | 10
8 | The DOGCOM 4s 850 mAh battery | 11
9 | The internals of a Combined needle roller / thrust ball bearing | 12
10 | The 6901ZZ roller ball bearing | 12
11 | The Needle Roller bearing | 13
12 | The 12 mm CF rod | 14
13 | The 3 mm PultrudedCF rod | 14
14 | The LM61460 in the VQFN-HR package | 17
15 | The TPS62932 in the SOT-583 package | 17
16 | The files for the schematic given by TI Workbench | 18
17 | The 3 pages of the schematic | 19
18 | The ”edge cuts” layer | 20
19 | The fixed items layer | 21
20 | The final layout depicting the placement of all the components | 22
21 | The 4 copper layers. Layer1 → 4 | 23
22 | The rendered PCB | 24
23 | The solder paste on the pads after being applied with a stencil | 25
24 | The Interactive HTML BOM Tool | 26
25 | The Bodge Wire | 28
26 | The Onshape assembly | 30
27 | The Front Wheel Adapter Pin | 31
28 | The Steering Knuckle | 32
29 | The Steering Column | 32
30 | The Top Brace | 33
31 | The Bottom Brace | 33
32 | The Side Brace | 34
33 | The Servo Horn | 34
34 | The Steering Links | 35
35 | The TPU Spacer | 36
36 | The Differential Gearbox | 36
37 | The Differential Gears | 37
38 | The Spider Center | 38
39 | The Housing for the Gearbox | 39
40 | The Attaching Cup | 40
41 | The Spacer Disk | 41
42 | The Rear Axle Assembly | 42
43 | The Front Mount | 43
44 | The Front Mount in the Slicer | 43
45 | The Back Mount | 44
46 | The Center Assembly | 45

47 | The Top Brace | 46
48 | The Bottom Left and Right Brace | 47
49 | The Left and Right Bearing mounts | 47
50 | The Lidar & ESC mount | 48

## 1 Selection of Components

### 1.1 Sensing

The WRO Future Engineers challenge sets certain criteria on the needed hardware. The second challenge makes teams not just detect walls but the pillars and their colors, as well as the ability to parallel park.

This means that a comprehensive and accurate inference of the playing field is required. There are multiple paths one can go down to fulfill this, there are perhaps only two practical routes. One is using distance sensors along with a camera and the other is using a 2-dimensional LiDAR.

The trade-offs between the two are fairly significant. The LiDAR comes at a higher cost than the camera and provides absolute and accurate cloud point data that can be used to detect the pillars and construct a map of the playing field with high accuracy. While the camera system is cheaper in the hardware cost, it has a significant cost in terms of compute. The detection of the actual pillars in the second round is easy, disregarding how slowly it would have to run and train (about 1/2 − 1 Hz for good reliability on a wide FOV camera running YOLO, taking about 3 hours to train on 300 images, and a variable time to compute, not real time), lacks in the accuracy of positioning the pillars in dynamic environments. The LiDAR also provides very accurate and fast (8 − 20Hz) feedback for absolute positioning on the go, something the camera does not. The aspect of parallel parking also plays into the advantage of the LiDAR. The LiDAR can provide a lot more detail than a distance assisted vision system could provide. If one did not use a LiDAR, atleast 4 mutually perpendicular distance sensor, Time of Flight or Ultrasonic, would have to be implemented on an I2C bus.

All this made the case for using the LiDAR stronger. On smaller scales, where the camera is quite a bit lager than the vehicle and so is the LiDAR, using a LiDAR makes sense due to the current lack of compute density for very small and light boards being an issue. But, for larger vehicles, where the cost of cameras scales linearly and the LiDAR scales exponentially, using multiple cameras and cheaper, larger compute makes sense. Hence, we decided to use a LiDAR for our vehicle.

However, this did come at a major trade-off and design cost. We had to keep the whole vehicle shorter than 80 mm to accommodate for a clear view of the laser at about 90 mm and have a clearance of 10 mm from the top of the 100 mm arena walls to account for deviations in the walls and potentially the playing field as well.

For the actual hardware, the YD-LiDAR X4 Pro was chosen due to it’s compatibility with ROS and it’s relatively low cost and high scanning speed along with it’s resolution. The X4 Pro provides the high range that is needed, extending from 8 centimeters to 10 meters. When measuring less than 8 centimeters, parallel parking for example, the fall further away will be utilized to interpolate. The USB interface of the LiDAR also was very handy along with the openly available library and drivers.


Figure 1: The YD-LiDAR X4 Pro.

Because the LiDAR only outputs the point cloud data, and we need to find the color of the pillars as well, a wide FOV camera is used in tandem. It is only used to determine the color of the pillar and not used for detection. The LiDAR detects the pillar and the image from the camera is then used to assign the color. This keeps the compute costs very low and allows for very fast inference. The camera used is the Arducam IMX219 Wide Angle Camera. It has a field of view of 175◦
. This allows us to have the maximum window for inference possible as we don’t need the data resolution a camera based solution would.

Figure 2: The IMX219 with a very wide angle lens.

### 1.2 Compute

The compute module doesn’t need to be something excessive like the Jetson Orion Nano. The compute required to complete both the challenges is fairly low and could be done on an STM32 H7 micro-controller as well. The compute module has to fulfill the following requirements:

1. Small form factor.
2. Have a USB poet.
3. Have a Camera Serial Interface .
4. Run ROS or Micro ROS.
5. Have a decent number of exposed IO pins for accessories.
6. Have the ability to read/write code for easy iterations.

This led to the Raspberry Pi 4B. Any other similar Single Board Computer (SBC) can be used. The 4GB RAM version was chosen so that a graphical user interface could be ran on it if needed when editing code during the competition. It would also provide sufficient headroom. A 2GB RAM version would have also been sufficient. A Raspberry Pi 5 would be overkill. The Pi 4 is also cheaper and easier to source. It would also have the compute needed to run the control loop at higher frequencies and have faster and more accurate control.

The only downside of the Rspberry Pi was it’s size. It’s a lot larger than needed, and occupies crucial space in the limited volume. This was solved with intentional and clever design. It’s availability of USB ports and the CSI makes it a very appealing solution. Custom hardware, ST based micro-controller or a board with the Raspberry Pi Compute Module, can be used but would be harder to source and would involve a longer development time. The Raspberry Pi also acts as a drop in solution as it has an external micro-SD card where all the code is stored, allowing for easy access and replaceability.


Figure 3: The Raspberry Pi 4 Model B.

### 1.3 Motion

A rear wheel drive system was chosen as it would distribute the complexity of the steering and drive systems, allowing easier manufacturing and assembly. The trade-off made here was that a differential would be required to prevent under steer that would be cause when turning at tight radii and slow speeds. This increases the complexity slightly, but not as much as using a drive and steering would need.

The motion system can be broken down into two parts, the drive system and the steering system.

### 1.3.1 Drive System

A brush less DC (BLDC) motor is proffered over a brushed motor due to it’s higher resolution of speed changes particularly at a low speeds. That comes particularly handy when parallel parking. It is also preferred due to its efficiency and torque. The ideal case would be a stepper or BLDC motor with Field Oriented Control (FOC) as it would provide excellent position and torque control, but sourcing such FOC motor drivers in a small and compact size is very hard and expensive. A note should be made that developing such a custom FOC motor driver for 10-20A should not be hard but would take time.

For the motor, a Surpass Hobby 36 mm diameter in runner BLDC motor is used. The 36 mm diameter is chosen as it provides enough torque, acceleration and internal breaking for a 1.5 kg vehicle. The length of the motor is 74 mm. This makes it a 3674 motor. The motor is also widely used in scale RC cars and hence is easy to source. The motor is rated at 1700 kv, which provides generous speed and high torque.

Figure 4: The Motor.

A Surpass Hobby 3 Phase 120A 4S ESC is used. This Electronic Speed Controller is preferred due to its high reliability and headroom, along with its configurability. The ESC can be configured to operate at certain speed, torque and braking levels with a configurator device.


Figure 5: The ESC.

Do note that if built again, a shorter motor and lower ampere rated ESC would be used, something like a 3650 motor and a 60A ESC. The 3674 motor is too long and has excessive torque that is not really needed. The shorter motor should be used to reduce the weight as much as possible. The ideal motor would be a 3650 motor rated somewhere about 1000 kv. The 60A ESC would also be chosen to reduce weight. The current setup was chosen because it is what was available without purchasing new components.

Figure 6: The Configuration Device that connects via PWM.

### 1.3.2 Steering System

A direct drive steering system was chosen for the vehicle, meaning that the servo directly drives the wheels. This was chosen as the steering links would be manufactured using 3D printing and each joint would cause additional backlash in the linkage mechanism. A system with a grater mechanical leverage would hence be more complex and less accurate, while taking more volume.

The S2500M servo motor is used, which provides a torque of about 25 kg
cm

at about 8V.
This would be provide ample headroom in a direct drive steering system. The only downside to contend with in this system is its weight and the fact that the servo runs on 8V, meaning it will need its own power supply. Do note that a lower torque servo that operates on 5V can be used if needed, the S2500M was available without purchasing new components.

Figure 7: The S2500M metal gear servo motor.

### 1.4 Power Management

The batteries were chosen on strict power consumption metrics. [Power usage table].

To provide adequate headroom for the 3+ minutes of operation needed, 2 DOGCOM 4S 850 mAh batteries were used in parallel. A single 4S 850 mAh battery in testing at full motion capabilities provided power for about 2.5 minutes before it went below the safe discharge voltage of 3.5 V per cell. Hence a second battery is needed for headroom.

The 4S batteries are used as they have the maximum voltage compatible with the setup, allowing the maximum acceleration and torque for the vehicle. The batteries use a Li-Po (Lithium Polymer) chemistry as that provides the high discharge current needed. It is also widely available and hence easy to source. On a larger scale vehicle, Li-Ion cells would be used due to their longer discharge cycle rating as the only major draw back with Li-Po batteries are their lower charge cycle rating.


Figure 8: The DOGCOM 4s 850 mAh battery.

### 1.5 The Additional Hardware

Additional hardware such as bearings and wheels are needed to build the vehicle. These are things that cannot be 3D printed and are manufactured in other ways or are sourced.

### 1.5.1 Bearings

For the two front steering knuckles, a thrust roller bearing is used. This is a type of bearing that combines a needle and thrust bearing in a single housing. It is used to constraint the location of the two front steering wheels though the axis of rotation and ensure there is no play present. If a normal roller ball bearing would be used, the outward and asymmetric torque of the wheel ”pin” would misalign the groove and the balls causing excessive play. The thrust roller bearing is a compact solution used in real cars as well.

The inner diameter of the bearing is 12 mm. It is the ”BCWN-T-d12-IR” bearing, sourced from JLCMC.

Figure 9: The internals of a Combined needle roller / thrust ball bearing.

For the differential, traditional roller ball bearings were used as the axial forces transferred are not that high. The 6901ZZ ball bearing is used as it is in a very compact package that has an internal diameter of 12 mm, an external diameter of 24 mm and a width of 6 mm, making it ideal to put in the already compact differential gear box.


Figure 10: The 6901ZZ roller ball bearing.

To support the rear axle, needle roller bearings are used. They are used as they have low friction and can withstand very high forces perpendicular to the axis of rotation, prefect for transferring the weight from the main body of the vehicle to the wheels. The ”BCWG-NK12/12” bearing was used, sourced from JLCMC. It has an inner diameter of 12 mm, an outer diameter of 19.5 mm and is 12 mm deep.

Figure 11: The Needle Roller bearing.

### 1.5.2 Carbon Fiber Tubes

Carbon fiber tubes were used at several places as axles, linkage connectors and structural connectors. This decision was made as carbon fiber has a very high tensile strength and is particularly very stiff perpendicular to it’s length.

A combination of 2 diameters were used. The axle for the rear two wheels were made using

### 12 mm outer diameter and 10 mm inner diameter carbon fiber tubes. Any aluminum or

steel shaft could be used here, but a 3D printed shaft cannot be used as the layer lines of the print would be perpendicular to the layer lines, leading to very weak prints. Carbon fiber was used as it is light weight and relatively easy to source in roll wrapped rods. This tube consists of ”twill” and not ”toe”.


Figure 12: The 12 mm CF rod.

The other rod used was a 3 mm outer diameter solid pultruded rod. It is used in the steering links as well as the structural spin that runs throughout the vehicle to provide stiffness to the frame and not let the printed parts sag. It is pultruded, meaning it does not consist of carbon fibers but of chopped carbon bits held by epoxy. It is comparatively less stiff but still very strong. It consists of ”toe” and no ”twill”.

Figure 13: The 3 mm PultrudedCF rod.

### 1.6 Wheels

On the market

## 2 PCB Assembly

The first question one should ask is why use a PCB at all? Why not just use jumper wires and other modules?

The answer is quite simple yet complex. A Printed Circuit Board (PCB) integrates all the power management components needed into a sleek and compact form factor without a lot of wiring. The Raspberry pi has a 20 × 2 pin interface, which isn’t very neat in it self. One can connect the individual jumpers to the header pins but it becomes VERY cumbersome very fast. Hence a PCB is almost necessary for a vehicle that can be easily serviced and is well engineered. Another major driver for this, as you will learn, comes from issues learnt from Siddesh’s participation in WRO the previous year. KiCAD was used as the eCAD tool to design the PCBs.

### 2.1 Purpose

When participating in WRO 2025, the SD Card we were using failed on us the day before the final competition. It was corrupted and the Raspberry Pi would not boot up at all. Turns out the issue was that that the Raspberry Pi was constantly undervolting under load. We had attempted to add a capacitor before the competition to resolve the issue, but the effort proved futile. Upon reviewing the logs, we confirmed that these undervoltage events were, in fact, what caused the SD card to fail. The buck converter was rated for 5V at a nominal current of 3A and a burst current of 5A. Yet the Raspberry Pi wouldn’t boot.

The Raspberry Pi needs a voltage higher that just 5V. It needs a voltage of about 5.15V to prevent the undervolting issue we had seen earlier. We searched the market for a buck converter capable of providing the 5.1V and 3A but I couldn’t find a suitable option. Hence it was determined that a custom solution was needed.

Hence the following considerations for the PCB were formed →

1. Deliver 5.15V to the Raspberry Pi and have a continuous rating of atleast 3-5A to power the LiDAR as well.
2. Deliver 8V to the servo motor at 2A.
3. Provide a better hardware interface than the 20 × 2 connector for the Servo and ESC.
4. Be compact and reliable.
5. Have additional expansion ports for Time Of Flight Sensors, and more Servos.
6. Integrate the power switch and start switch, along with indicator LEDs needed for the rules on to the board.
7. Look good!

### 2.2 Form Factor

The first thing to decide after deciding the purpose is to decide the form factor of the PCB. This in turn, will decide where the PCB will live.

The best form factor is having the PCB as a hat above the Raspberry Pi itself. This is because of the following reasons →

1. There is a relatively large space above the Raspberry Pi, somewhere about 65 mm × 56 mm.
2. A simple header pin board can be added to the PCB, meaning it will directly interface with the header pins on the Raspberry Pi. This would eliminate the need for adding wires between the Pi and the PCB, ensuring efficient and smooth power distribution and connections.
3. It would provide ease of maintenance to the PCB and uninterrupted access to the switches.

### 2.3 Selection of the ICs

Due to the custom need for the 5.15V and a lack of existing modules, a custom voltage converter module would have to be implemented on the PCB hat. Since we were already using SMD (Surface Mount Device) components for the 5.15V PCB, we decided to integrate the 8V part as well on the PCB itself rather than have a separate module.

We use buck converters, which are a form of switching regulators rather than using linear regulators. Although linear regulators provide the smoothest possible voltage, they dissipate the remaining energy as heat, and hence are very inefficient and only good for low power applications where the voltage difference between the input and output is very low. However, we need the exact opposite. We need to draw an insignificant current and our voltage difference between the input and output is substantial. Hence we use switching regulators. The only downside is that they do not have a clean voltage output as they use a MOSFET to switch at between 0V and battery voltage at high frequencies. This can be compensated for using good design and with adding filtering capacitors at the output.

### 2.3.1 The 5.1V Rail

The LM61460 from Texas Instruments was chosen as the switching regulator due to its size and the fact that it has a continuous limit of 6A. It is also ideal because it has symmetric switching nodes and in built MOSFETs, which reduce noise.


Figure 14: The LM61460 in the VQFN-HR package.

The values for the schematic were obtained using the TI Workbench.

### 2.3.2 The 8V Rail

The TPS62932 from Texas Instruments was chosen as it is incredible small and has a current rating of 2A. It also has an in built MOSFET in its incredible tiny package of just 2.1 mm × 1.6 mm.

Figure 15: The TPS62932 in the SOT-583 package.

The values for the schematic were obtained using the TI Workbench.

### 2.4 The Schematic

The first stage of the PCB development process is creating the schematic; the wiring diagram for all the connections. The first step is to add all the individual components that are used, the Raspberry Pi, the buck converter ICs, the motors, the LEDs, the switches, the power connectors and any other I/O that maybe needed.

The switching regulators need additional hardware, such as resistors and capacitors along with an inductor. The value of these components decide what voltage you get at the output. To find these values, the TI workbench tool was used. The TI workbench allows one to configure the parameters and then produces a schematic (Figure 16). This is then used to set the value and the connections of the SMD components.


Figure 16: The files for the schematic given by TI Workbench.

The schematic (Figure 17) created is in 3 pages. The main page has the XT30 power connector input and the power switch. The Raspberry Pi page consists of the Raspberry Pi, the sensors and I/O devices. The power page consists of all the power regulation circuitry. It also has 2 additional electrolytic capacitors, one 220µF and the other 270µF. They both act as decoupling capacitors for the Raspberry Pi and the servo respectively. They ensure that when there are load spikes from either devices, the Raspberry Pi booting or the servo starting to move, the spike does not reach the ICs and is handled locally.


Figure 17: The 3 pages of the schematic.

The PDF for the Schematic can also be found in the PCBA folder. The BOM for all the parts is also available there, along with the manufacturer used.

### 2.5 The Layout & Routing

This step is very crucial, it is responsible for how well the components interact with each-other and determines how clean your output voltage is. A 4 layer board was chosen. This was done as it would make the routing easier across multiple layers and because a 4 layer stack up is recommended in the LM61460 data sheet.

All the SMD components would be place on one side of the board so that the board could be assembled on a hot plate. This would also aid with the ease of assembly. The following is the stack up →

1. Layer 1: It carries much of the important signals, especially for the buck converters.
2. Layer 2: A solid Ground plane to reduce EMI and act as a fast return path of the top player.
3. Layer 3: The Power plane consisting of the input voltage, 5.15V and 8V.
4. Layer 4: A Ground plane that also carried some of the signals from the Raspberry Pi.

The first thing to do is create the board outline. A rounded rectangle with length 65mm, height 56mm and a corner radius of 2mm was chosen. A 6mm notch was then removed from the bottom right of the board to allow the camera ribbon cable to pass through. Figure 18 shows the shape of the board.

Figure 18: The ”edge cuts” layer.

After this, the fixed components are place, such as the mounting holes for the board and the 20 × 2 female header pin that connects to the Raspberry Pi. These need to be incredibly precise as they are the locating hardware for the hat to connect on to the Raspberry Pi. M2.5 holes are used.


Figure 19: The fixed items layer.

The next part is the most cumbersome. All the physical parts need to be laid out in a manner that ensures the most ideal connections possible. The 3 main current loops; ON-State Current Loop, OFF-State Current Loop and The ”Hot Loop”; of the buck converter need to be kept as short as possible. Since we are using a symmetric buck converter, it also needs to be made sure that the power lines to both sides are as similar as they can be. The path between the switching node and the inductor needs to be as short as possible. All the connectors need to accessible.

For this reason, the power connector (XT30) and the power switch were placed on the right side. The switching circuitry was spread around the middle. The second switch and the connectors for the motor and servo were kept on the left side. The electrolytic capacitors were placed as close to the outputs as possible. The LEDs were also placed in the middle. The extra components, such as the connectors for the 2 ToF sensors and an extra PWM connector were kept on the bottom and bottom right respectively. Figure 20 shows the layout of the final board. It is fairly crammed but a lot more items, such as more LEDs, Current and Voltage sensing and a CAN BUS port can also be added in the future.

Figure 20: The final layout depicting the placement of all the components.

Figure 21 shows the actual copper layers as they are. Copper pours are preferred whenever possible. They also help with thermal management. It was made sure that there were no wires beneath the two inductors to make sure all the signal traces are as clean as possible.


Figure 21: The 4 copper layers. Layer1 → 4.

Some art work and quotes were added to the free space to ensure complete utilization and occupation of left over space. A black solder mask was chosen. Figure 22 show the PCB rendered in the KiCAD 3D viewer. The contribution for the art work goes to M.C. Escher.

Figure 22: The rendered PCB.

The PCB was manufactured by JLC. JLC was chosen due to their lower cost for black solder mask compared to Indian manufactures. The following are the basic parameters:

1. Base material: FR4
2. PCB Thickness: 1.6mm

3. PCB Color: Black
4. Silkscreen: White
5. Material Type: FR4 TG135
6. Surface Finish: Lead Free HASL (Hot air solder leveling)

### 2.6 Assembly

The assembly was done by hand. 0603 class components are not too hard to place by hand. Alternatively, assembly can be done by the manufacturer as well.

A stencil was used to apply the layer of 183◦ C solder paste on to the board with the help of an old credit card. The ”Interactive Html Bom” plugin (Figure 24) was used to aid with assembly. The plugin creates a interactive html file that can be used to figure out the placement of the components. Alternatively, the PCB and schematic editor can itself be used to figure the placement out but using the plugin is recommended do to its convenience. Once the components have been laid out, a final visual inspection can be carried out.


Figure 23: The solder paste on the pads after being applied with a stencil.

The boards can then be re-flowed on the hot plate. It is recommended to follow the heat curve of the solder paste being used. If the plate available does not have the ability to follow a curve, let the board heat soak at about 50-80◦ C below the melting point of the solder paste for about 1-2 minutes to let the flux activate before increasing the temperature to its final point.

Our hot plate did not have the feature to follow the heat curve so we let our boards soak at 130◦ C for 90 seconds after increasing the temperature to 195◦ C till all of the paste re-flowed and waited 30 seconds more before taking the boards off the hot plate.

Figure 24: The Interactive HTML BOM Tool.

The HTML file generated by the plugin can be found in the PCB folder along with the BOM.

Once this is done, the through hole components; like the switches, the power connector and the 20 × 2 header connector; can be soldered on to get the final board.

Note: Please refer to the next subsection, Mistakes & Errors before powering on the board. There is a 1000 µF capacitor to be added between the output of the switch and GND.

### 2.6.1 Advice

The following is the recommended order for the placement of the components ⇒

1. U1
2. U2 (be careful, some wiggling around is needed)
3. C8, C9
4. C1, C2, C3, C4
5. C5, C6, C7
6. C18
7. R1
8. R2, R5

9. R3
10. R4
11. C10
12. C11
13. C13
14. C12, C14, C16
15. C15
16. C17
17. R7
18. R6
19. L2
20. L1
21. C19
22. C20

### 2.7 Mistakes & Errors

The first iteration, V1.0, had a fatal flaw. During the schematic design, the enable pin of the LM61460 was connected to ground. The enable pin needs a voltage of greater than about 3V. This mean that the chip would be in the ”shutdown mode”. This mean it would not work at all.

To attempt fix this issue, the trace from the GND via to the EN pin was cut off using a razor blade. A thin copper wire (32 AWG) was then added very carefully between the VIN and the EN pad. Typically, this is called a ”bodge” (Figure 25). This turned out to be very unsuccessful. This was because of the Package of the IC and the microscopic, but still substantial thickness of the wire. The VQFN package has flat pins at the bottom that interface with the surface directly (Figure 14). This meant that while the wire was fairly thin, its thickness meant that not all the pins of the IC made contact with the PCB. It was sort of like a see saw. Another attempt was made with a thinner strand of wire, about a third of the diameter but that was also unsuccessful.

Hence the decision was made to re order a new set with the fixed connections, V1.1. The original error was traced down to a mistake in copying the schematic from TI workbench to the KiCAD schematic editor.


Figure 25: The brown area on the top right of the copper wire represents the cut out trace.

The newer version, V1.1 was assembled successfully and worked flawlessly, providing 5.15V to the Raspberry Pi as intended. During hardware testing, when using the switch to power on and off the Raspberry Pi, the LM61460 chip, literally, burst into flames and released the magic smoke. This was right as the switch had been toggled to the on position, triggering a catastrophic hardware phenomenon known as an LC hot-plug transient spike. The wires from the battery inherently act as an inductor, and the ultra-low ESR (Equivalent Series Resistance) ceramic input capacitors on the board act as a capacitor, together forming an undamped LC resonant circuit. When the mechanical switch was flipped, its internal contacts bounced microscopically. This rapid connect-disconnect action, combined with the near-zero resistance of the ceramic capacitors, caused the sudden inrush current to ring like a bell. The voltage overshot significantly, effectively doubling the 16.8V battery input and easily punching through the 36V absolute maximum rating of the LM61460.

This destructive spike was further amplified by the DC bias derating of the ceramic capacitors, which temporarily lose capacitance under high voltage, forcing the transient spike even higher. The fix for this required introducing a ”shock absorber” to dampen the resonant circuit. By adding a 1000 µF electrolytic capacitor directly between the output of the switch and ground, the naturally higher ESR of the electrolytic component safely dissipated the kinetic energy of the inrush current as microscopic heat. This completely arrested the pendulum swing of the LC ringing, clamping the voltage safely to the battery level and bulletproofing the circuit against future switch bouncing.

NOTE: The PCB design files do not include this fix, and it is to be implemented after.

## 3 3D Prints & CAD

The body of the vehicle is primarily made up of 3D printed parts. Onshape was the CAD package used. Extreme considerations were made when designing the vehicle. Ease of reputability, along with structural rigidity were the utmost priority when designing the parts. This was exasperate from the constraints already present when using FDM (Fused Deposition Modeling) 3D printing.

Tolerances for the parts were borrowed where ever possible as a foundational design principle to ensure predictable and consistent assembly. Because FDM printing is inherently prone to dimensional variations; caused by thermal shrinkage, layer lines, and extrusion inconsistencies; calculating unique clearances for every single joint is highly inefficient and risks assembly failure.

By standardizing and ”borrowing” proven tolerance profiles (such as a baseline 0.2mm gap for slip fits and 0.4mm for clearance holes) across the entire CAD model, the design creates a modular, standardized system. This strategic allocation allows non-critical dimensions to absorb the printer’s inherent inaccuracies. Ultimately, this prevents tolerance stack-up issues and guarantees that structural interfaces bolt or snap together seamlessly on the first print, eliminating the need for tedious manual post-processing, filing, or reprint iterations.

Pre-flight and Orca Slicer were the Slicers used for the conversion of the 3D files into G-Code. The utmost care was given to the parts in the design process. There are no large parts that need a massive printer to be printed. All the parts can fit on a minimum build volume of about 150 × 150 × 150 mm. The whole assembly was created in Onshape to ensure parts fit together seamlessly.

### 3.1 Layout & Wheelbase

To adhere to the strict volume limitations we set in the introduction, a slightly wider wheelbase was opted compared to what most competitors would probably use. This was done so that more horizontal volume could be allotted to the components without shifting them vertically. A strict horizontal width limit was put at 180mm to ensure the 200mm limit was not breached. The wheels where placed as far out as possible to maximize component volume and have better stability.

A wheelbase of 184.3mm was chosen. A longer wheelbase would mean that the vehicle would have trouble parallel parking. The number 184.3, may seem odd but it was derived from scaling the Aston Martin Valkyrie down to the size of the wheels being used.

The layout, as mentioned earlier, a Rear Wheel drive mechanism with front wheel steering was chosen. This made the layout slightly easier but it was crammed nevertheless. Figure 26 shows the CAD assembly, moving top down.

Figure 26: The Onshape assembly.

Starting at the front, we have the camera as the front most element. This is driven by the fact that the camera has a very high FOV and the best view would be unobstructed. Just behind it is the front axle. It houses the steering system and the bearings. In the center there sits the LiDAR, directly positioned on top of all the components. Below the LiDAR, with a healthy amount of spacing to prevent EMI is the motor. To the right of the motor, the ESC is mounted vertically. The Raspberry Pi is mounted on the left side of the motor. Moving further back, we reach the differential and the rear axle. The batteries sit atop the rear axle baring mounts.

It was critical for every single part to be accounted for. All the models were self designed. There are a few critical assemblies that need to be discussed in order.

### 3.2 The Steering Assembly

Front Wheel Adapter

The steering assembly originates from two points in space, the contact points for the needle roller thrust bearings (Figure 9). The bearings connect to the wheels via a rod that is capped at on end. The rod as a nominal diameter of 12mm and a length of 38mm. The cap at the end has a diameter of 20mm and a width of 3mm. The rod also has a 2mm hole at the end, spaced 4.5mm from the edge of the non capped end to interface with the wheel (Figure: ??) via a M2 screw.

Figure 27: The Front Wheel Adapter Pin.

The pin is printed vertically, with the cap end facing down. This does spread the load across the layer lines, the load on the front wheels isn’t drastic enough for one to be concerned. The part is printed with a layer height of 0.2mm, has 3 perimeters and a 25% infill.

Steering Knuckles

We next interface with the stationary parts of the bearing. To do this, we make a clamp style part that relies on the pressure and friction to keep the bearing constrained. We replicate the grove in the bearing as a positive feature to constrain the bearing axially.

Figure 28: The Steering Knuckle.

To interface the two part clamp, we use two M3 × 12 screws and M3 nuts. We flatten out the sphere at 31mm so that the clamps can interface with the other steering parts and rotate in the vertical axis. To do this, we add a 2.8mm hole on the top for a M3 screw. We keep the hole smaller than the screw diameter so that the screw can create the threads in the plastic part as it enters. This is done as using a heat set inset would take too much space. Also it is justified by the lower loads. We also add a 2.5mm hole so that a screw can be added for the steering rod interface. These would be like Steering Knuckles in a traditional car. It is mirrored to fit on the left side.

The part is printed with the face closest to the bearing (and image in Figure 28) facing down. This not only transfers the loads along the layers but also ensure a good interference fit with the bearing. The part is printed with a layer height of 0.2mm, has 3 perimeters and a 25% infill.

Steering Column

The steering column consists of 4 parts (See Figure 29), the top brace (light blue), the bottom brace (grey) and 2 side braces (dark blue). It mounts the servo on the center of the front axle and provides interface points with the rest of the vehicle.


Figure 29: The Steering Column.

The top brace is the largest part in the steering column. It mounts the servo and the camera. The servo mounts via 4 M3 × 20 screws and has a mounting pattern of 10.5 × 48mm. The top brace has an hole at each extreme so that it can interface with the steering knuckle. It does so by using M3 × 8 screws. The holes are space 131mm apart. The top brace has 4 additional counter bore holes that connect it with the 2 side braces. On the rear face of the mount, there are two locating holes for the carbon fiber rods that are spread apart by 36mm. There also exists a flat face with space for 2 M3 × 6 heat set inserts so that the part can interface with the rest of the body and is constrained.

Figure 30: The Top Brace.

The part is printed with the top face (See Figure 30) facing down, at a layer height of 0.2mm, has 3 perimeters and a 25% infill. The part nominally includes features to aid with counter bore bridging but PreFlight can also be used to aid with this.

The bottom brace is the simplest part. It is a slightly curved piece that spans the breadth of the wheelbase. It has 4 countersunk holes, 2 to interface with the steering knuckles, and 2 to interface with the side braces, using M3 × 8mm countersunk and M3 × 10mm countersunk screws respectively. The part is printed with the bottom face (See Figure 31) facing up, so that the sunk bores are not printed as overhangs. It is printed at a layer height of 0.2mm, has 3 perimeters and a 25% infill.

Figure 31: The Bottom Brace.

The side braces are slightly more complex in geometry as they are a product of lofts. The side braces have spaces for 2 M3 × 6mm brass heat set inserts on the top, and 1 M3 × 6mm brass heat set inset on the bottom to interface with the top and bottom braces receptively. The side brace also has a feature to interface with the bottom set of 3mm Carbon Fiber Rods. The part is designed for the left and is mirrored to fit for the right side. The part is printed with the top surface facing down, at a layer height of 0.2mm, has 3 perimeters and a 25% infill.

Figure 32: The Side Brace.

They all combine to form the steering column.

Servo Horn

The servo horn is the part that clamps on the the shaft of thew servo and interfaces with the steering linkage rods. It is a fairly simple part. It houses a 6mm hole at one end and the space for a M3 × 6 spacer (See Figure 33, grey) that is press fit into it. The distance between the two is 30mm. The height of the part is also 6mm. The part is printed at a layer height of 0.2mm, has 3 perimeters and a 25% infill. To maximize the frictional force, the inside surface of the hole is printed with Fuzzy Skin, with a thickness of 0.1mm and 0.2mm.


Figure 33: The Servo Horn.

Steering Links

The steering links, along with a 3mm Carbon Fiber rod make up the steering rod. The links have 2 parts (See Figure 34), one that connects to the servo, the servo link (Figure 34a) and the other other that connects to the knuckle (Figure 34b), the wheel link. The servo link has a height of 7.1mm with a 3mm hole running through the center for a M3 × 10mm screw. It also has a space for the carbon fiber rod perpendicular to the screw. The wheel link is similar with a height of 5mm and a hole for a M2.5 × 18mm screw that connects it to the steering knuckles. The two links rely on the screw as a ”pin” to rotate freely. A bearing is not used for this revolute joint as the size is too small to accommodate any and the force are low. The part is printed at a layer height of 0.12mm, has 3 perimeters and a solid infill. 2 sets of these are needed to form the 2 steering rods. One is mounted at the top and the other at the bottom (Figure 34c).

(a) Servo Link
(b) Wheel Link | (c) Installation Context

Figure 34: The Steering Links

TPU Spacer/Shim

A Outer 16mm and inner 12.80mm spacer, with a height of 6mm is needed. This sits between the bearing and the wheel and provides pre-load to the whole stack up. This is used as the roller thrust bearing is only constrained in one direction by the end cap. The other end is hence constrained by the TPU spacer and the pre-load it provides. The pre-load also ensures there is as little play between the axle and the bearing as possible. Figure 35 (red) shows the placement of the spacer in section view. Since it is made out of a flexible material with a shore hardness of 95A, the height of the spacer determines the pre-load force. The part is printed at a layer height of 0.2mm, has 3 perimeters and a solid infill. It is utilized on both sides.


Figure 35: The TPU Spacer.

This concludes the assembly of the front axle. The length of the 3mm carbon fiber rod used in the steering links is ≈ 48mm. It is glued to the steering links.

### 3.3 The Differential

Figure 36: The Differential Gearbox.

As mentioned earlier, a differential gear box is used. The center of the gearbox is formed by the ”spider” gears and the carrier along with the main gearbox. In a differential gearbox, the housing containing the spider and main gears also rotates and is mounted to a stationary mount. The housing contains the main gear reduction for the differential. The spider gears assist with the difference in speeds of the two main gears (and hence wheels). All of the parts of the gearbox are 3D printed. The net reduction produced is 8 : 28 = 2 : 7.

The Gears

The differential consists of 3 spider gears and 2 main gears All the gears present are bevel gears created using the OnShape bevel gear scripts.

The spider gears have 9 teeth, a module of 1.5mm, a pressure angle of 20◦ and a bevel angle of 30.96◦
. The spider gears have a 3mm hole through the center to interface with the axle. The top has be flattened to aid with printing. They are set 120◦ apart. See Figure 37a.

The main gears have 15 teeth, a module of 1.5mm, a pressure angle of 20◦ and a bevel angle of 59.04◦

. Notice that the bevel angles of the 2 types add up to 90◦
. The main gear transfer
all the load to the wheels. Hence, using a single screw in the center would cause it to loosen due to the torque caused. Hence, 2 screws are use that are placed 3mm apart from the center to connect the gears to the part that interfaces with the rear axles. Behind the gear sits a 12mm ×11mm cylinder that interfaces with the bearings. The top has be flattened to aid with printing. See Figure 37b.
(a) The Spider Gear


(b) The Main Gear | (c) Installation Context

Figure 37: The Differential Gears

All 5 of the parts are printed at a layer height of 0.12mm, has 3 perimeters and a solid infill.

A brim is used to aid with bed adhesion. The spider gears and the main gears are printed with the gear face facing down. This means that the forces of the gears runs along the layer. However, this means that the rotational force of the main gear to the wheels runs across the layer lines, which would mean that the are where the gear ends and the cylinder starts is the weakest area. To counter this, the M3 × 20 button head screws that are used to connect the main gear and the axles run all the way to the end of the gear, meaning they transfer most of the rotational loads and strengthen the part’s function across the layer lines. See figure 37c.

The Carrier/Spider Center

The Spider Center is the part that holds all the spider hears in the center and aligns them. In the housing, it is suspended by the M3 × 10mm Button Head screws. See Figure 38.

It’s a filleted triangle with 3 3mm holes on each side. It has a height of 6mm. It is printed at a layer height of 0.12mm, has 3 perimeters and a solid infill. A brim is used to aid with bed adhesion. The part can be printed on either of the larger, flat surfaces.


(a) The Part. | (b) The Spider Center in Action.

Figure 38: The Spider Center.

Housing

The housing for the differential gears consists of 2 halves, the left half and the right half. The two halves are connected by 3 M3 × 30mm screws and M3 nuts (See Figure 36).

The housing not only houses the gears but also 2× 6901ZZ bearings (Figure 10). This is to decouple the rotation of the main gears with the rotation of the housing when the two axles are spinning at different speeds. The left housing and the right housing are nearly identical. The left housing houses the bevel gear ring needed to rotate the differential housing using the motor. That gear has 28 teeth, a module of 1.5mm and a bevel angle of 70◦
. In Figure 39, the left housing is the one in light blue and the right housing is in dark blue. The bearings sit inside the housing.

The part is printed with the center surface of each of the half facing down. Looking carefully, a chamfer is present on the end where the bearings sit. This allows for the overhangs to be managed better. It is printed at a layer height of 0.12mm, has 3 perimeters and a 25% infill. A brim is used to aid with bed adhesion.


Figure 39: The Housing for the Gearbox.

The Attaching Cups

The Cup is the part that interfaces with main gear and the 12mm carbon fiber tube that serves as the rear axle. It has the same mounting patter as the Main gear (6mm spacing between the 2 M3 screws). The Cup extends the 12mm cylinder outward to house the 12mm rod. It also has 2 × 2mm holes at each end to interface with the axle and transfer the load.

For printing, the cup is split into 2 parts axially (see Figure 40) and then printed flat to ensure the force moves along the layers and ensure ease of printability. It is printed at a layer height of 0.12mm, has 3 perimeters and a 25% infill. A brim is used to aid with bed adhesion.

Figure 40: The Attaching Cup.

The Spacer

When looking at Figure 36, one can see that there are bearings on the outside as well, excluding the ones inside the housing. These are also 6901ZZ bearings and are responsible for the rotation of the housing itself. They are clamped from either end (discussed later). To ensure that there is →

1. No play in the mounting of the differential gearbox
2. Adequate separation between the bearing ends and the housing of the wall
3. Ease of motion

A spacer disk is mounted in between the two bearings. This disk also provides the pre-load needed in the gearbox stackup. It also ensures that the main gears in the differential mesh properly with the spider gears. Unlike the TPU spacer (Figure 35), this is made out of PLA.

It is printed at a layer height of 0.12mm, has 3 perimeters and a 25% infill. A brim is used to aid with bed adhesion. The height of the disk, nominally 2.00mm can be adjusted to adjust the pre-load. The grove of the roller bearing (Figure 10). The disk has an outer diameter of 16.40mm and an inner diameter of 12.4mm. You can see the orange disk in Figure 41 doing its job.


Figure 41: The Spacer Disk.

### 3.4 The Rear Axle

The rear axle is what really brings everything together. The mounts for the rear axle hold the motor, the batteries, the needle roller bearings and the differential. They are also the end point of the 4 carbon fiber rods used to strengthen the vehicle. The parts for the rear axle are also among the largest parts.

The rear axle houses the 2 BCWN-T-d12-IR bearings (Figure 11). We start our journey with the Rear Axle Mount. It encompasses the whole rear axle and only consists of 2 parts that work in tandem.

Figure 42: The Rear Axle Assembly.

Rear Axle Mount Front

The front mount is the light blue colored part in Figure 42. It houses the motor and serves as one half of the gearbox mount. It is one of the most complex parts.

It houses holes for 6 M3 × 8mm screws that connect the motor to the mount. It also has space for 4 M3 × 4mm heat set inserts at the very end to interface with the back mount and space for 6 M3 × 6mm heat set inserts, 3 on each side (see Figure 43) that allow it to interface with the parts that connect the front and the rear axle. The front mount also serves as the end point of the bottom set of 3mm rods.

The part is printed with the forward facing face in Figure 42 pointing down, as shown in Figure 44. The part does need supports at the area where the motor mounts. It is printed at a layer height of 0.20mm, has 3 perimeters and a 25% infill. A brim is used to aid with bed adhesion.


Figure 43: The Front Mount.

Figure 44: The Front Mount in the Slicer.

Rear Axle Mount Rear

The rear mount serves as a half to mount the BCWN-T-d12-IR as well as the 6901ZZ bearings. It’s a fairly chunky piece. It uses 8 M3×8mm screws that interface with the rest of the vehicle. This part serves as the end mount of the top 3mm carbon fiber rods.

The part prints with the front face facing downward. It is printed at a layer height of 0.20mm, has 3 perimeters and a 25% infill. A brim is used to aid with bed adhesion and prevent warping. Supports are not needed but appreciated.

Figure 45: The Back Mount.

The batteries mount above the rear axle and are shown in the next section.
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

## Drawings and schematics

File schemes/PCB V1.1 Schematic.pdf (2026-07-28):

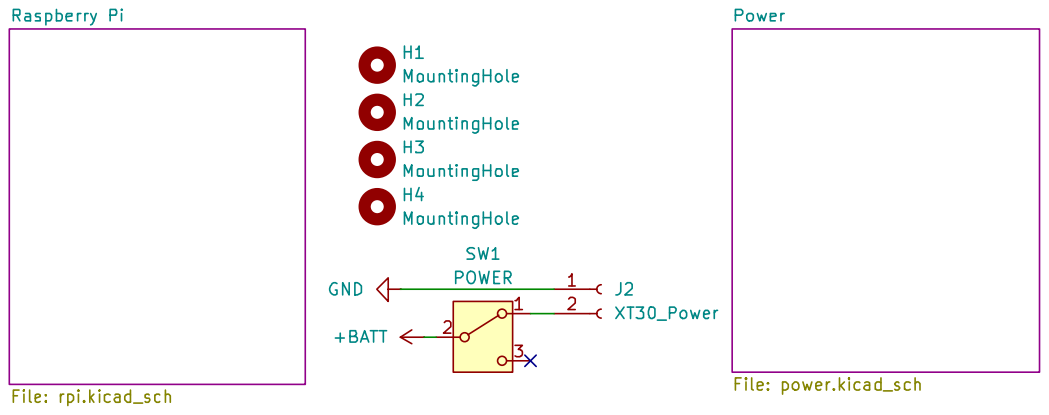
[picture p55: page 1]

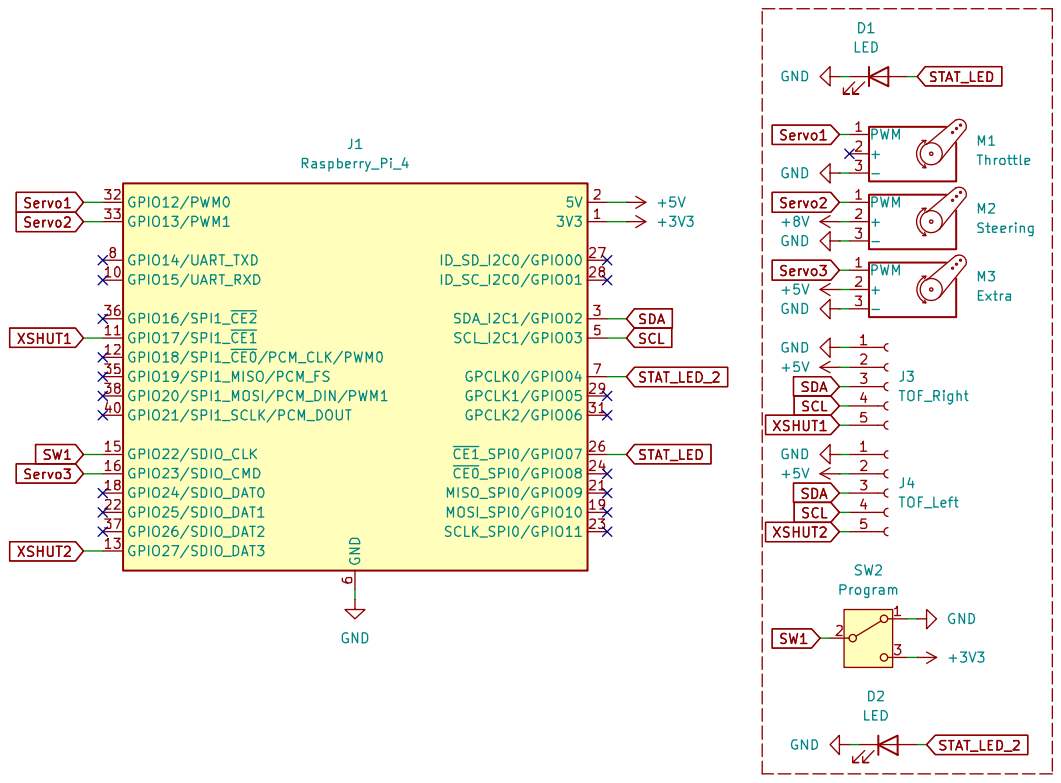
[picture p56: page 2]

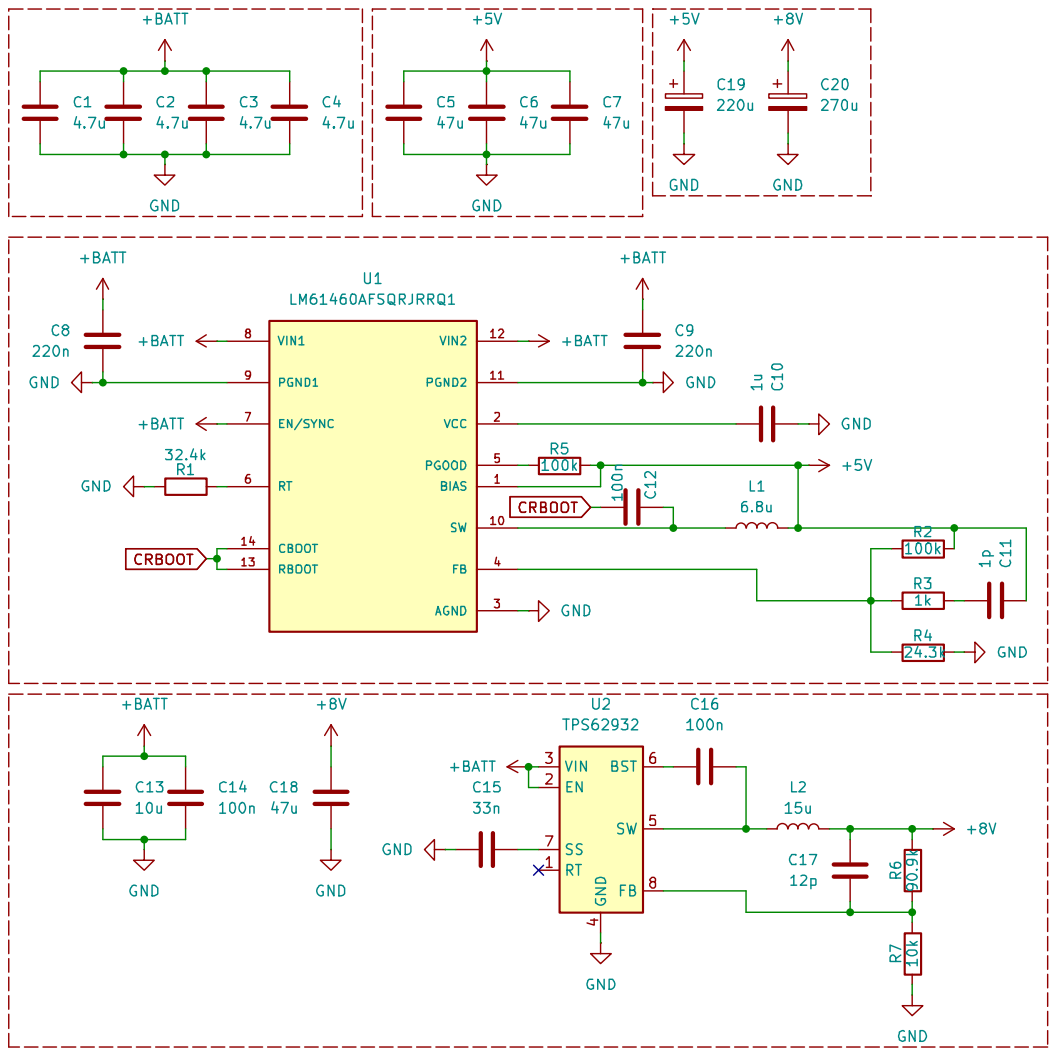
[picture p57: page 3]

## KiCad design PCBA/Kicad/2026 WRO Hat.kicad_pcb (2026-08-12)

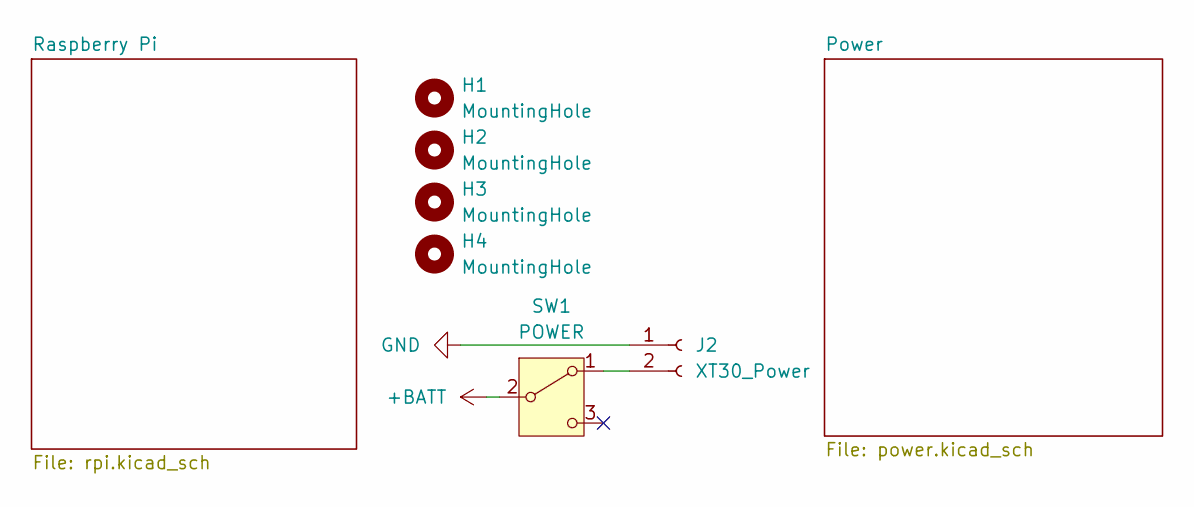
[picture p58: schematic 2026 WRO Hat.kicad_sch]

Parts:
H1, H2, H3, H4: MountingHole; MountingHole_2.5mm_Pad_TopBottom
J2: XT30_Power; AMASS_XT30PW-M_1x02_P2.50mm_Horizontal
SW1: POWER; Switch

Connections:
+BATT: SW1.2 (B); also elsewhere on the board
GND: J2.1; also elsewhere on the board
unnamed: J2.2, SW1.1 (A)

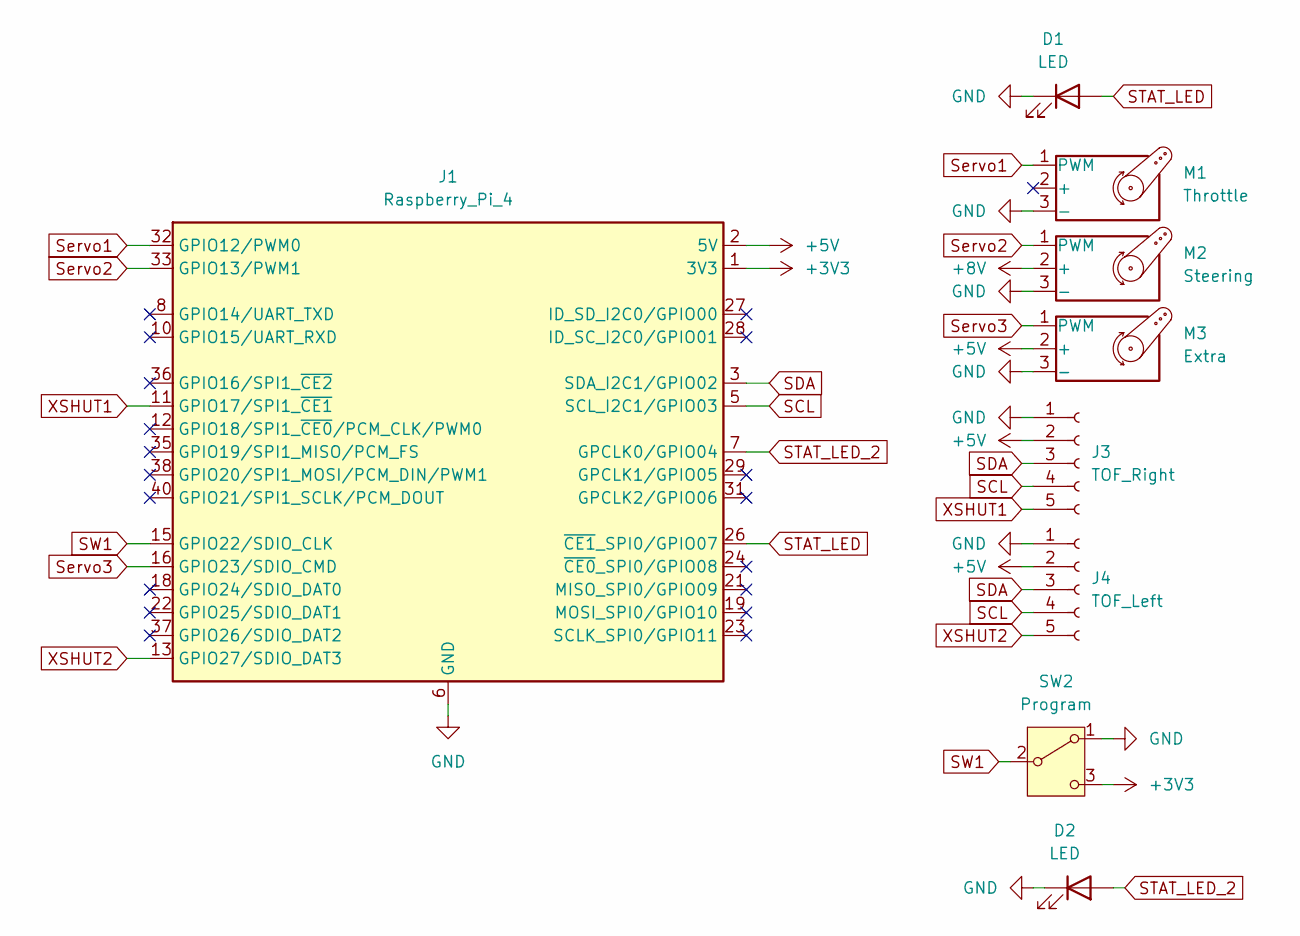
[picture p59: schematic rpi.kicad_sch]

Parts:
D1, D2: LED; LED_D5.0mm
J1: Raspberry_Pi_4; PinSocket_2x20_P2.54mm_Vertical
J3: TOF_Right; PinHeader_1x05_P2.54mm_Vertical
J4: TOF_Left; PinHeader_1x05_P2.54mm_Vertical
M1: Throttle; PinHeader_1x03_P2.54mm_Horizontal
M2: Steering; PinHeader_1x03_P2.54mm_Horizontal
M3: Extra; PinHeader_1x03_P2.54mm_Horizontal
SW2: Program; Switch

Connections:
+3V3: J1.1 (3V3), J1.17 (3V3), SW2.3 (C)
+5V: J1.2 (5V), J1.4 (5V), J3.2, J4.2, M3.2 (+); also elsewhere on the board
+8V: M2.2 (+); also elsewhere on the board
GND: D1.1 (K), D2.1 (K), J1.6 (GND), J1.9 (GND), J1.14 (GND), J1.20 (GND), J1.25 (GND), J1.30 (GND), J1.34 (GND), J1.39 (GND), J3.1, J4.1, M1.3 (-), M2.3 (-), M3.3 (-), SW2.1 (A); also elsewhere on the board
SCL: J1.5 (SCL_I2C1/GPIO03), J3.4, J4.4
SDA: J1.3 (SDA_I2C1/GPIO02), J3.3, J4.3
STAT_LED: D1.2 (A), J1.26 (~CE1_SPI0/GPIO07)
STAT_LED_2: D2.2 (A), J1.7 (GPCLK0/GPIO04)
SW1: J1.15 (GPIO22/SDIO_CLK), SW2.2 (B)
Servo1: J1.32 (GPIO12/PWM0), M1.1 (PWM)
Servo2: J1.33 (GPIO13/PWM1), M2.1 (PWM)
Servo3: J1.16 (GPIO23/SDIO_CMD), M3.1 (PWM)
XSHUT1: J1.11 (GPIO17/SPI1_~CE1), J3.5
XSHUT2: J1.13 (GPIO27/SDIO_DAT3), J4.5

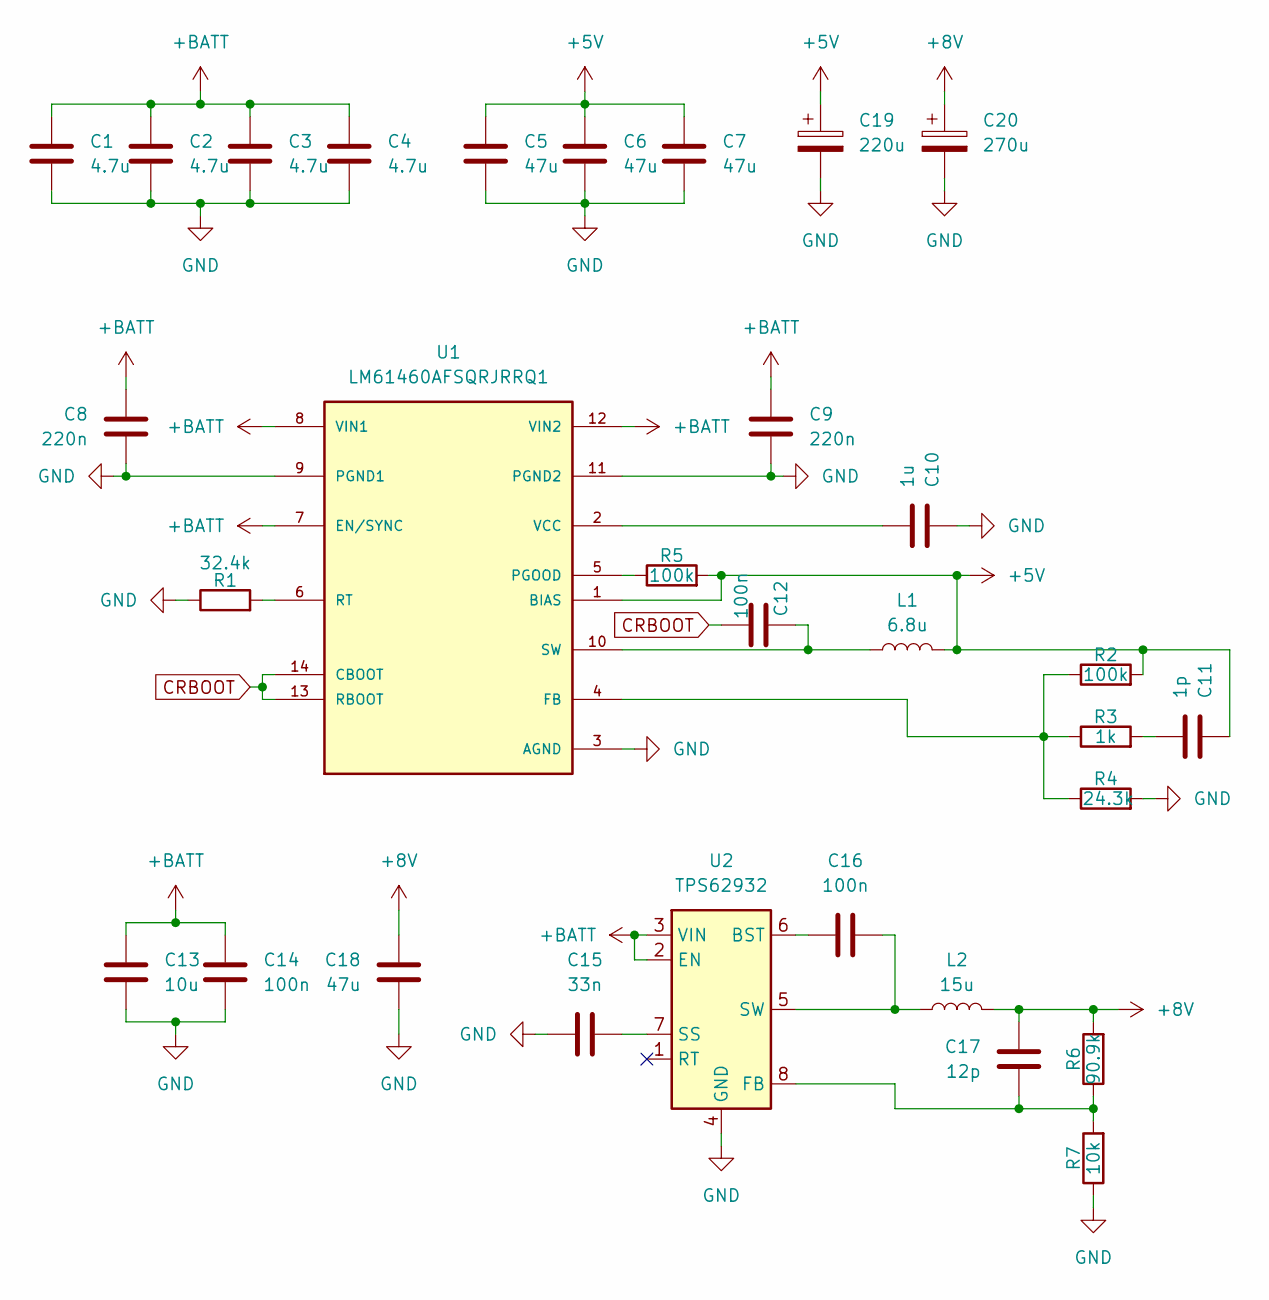
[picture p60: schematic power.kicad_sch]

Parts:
C1, C2, C3, C4: 4.7u; C_0603_1608Metric
C5, C6, C7: 47u; C_0603_1608Metric
C8, C9: 220n; C_0603_1608Metric
C10: 1u; C_0603_1608Metric
C11: 1p; C_0603_1608Metric
C12, C14, C16: 100n; C_0603_1608Metric
C13: 10u; C_0603_1608Metric
C15: 33n; C_0603_1608Metric
C17: 12p; C_0603_1608Metric
C18: 47u; C_0805_2012Metric_Pad1.18x1.45mm_HandSolder
C19: 220u; CP_Elec_8x10; LCSC C341198
C20: 270u; CP_Elec_10x10; LCSC C251008
L1: 6.8u; L_Chilisin_BMRF00101040
L2: 15u; L_Chilisin_BMRB00060618
R1: 32.4k; R_0603_1608Metric
R2, R5: 100k; R_0603_1608Metric
R3: 1k; R_0603_1608Metric
R4: 24.3k; R_0603_1608Metric
R6: 90.9k; R_0603_1608Metric
R7: 10k; R_0603_1608Metric
U1: LM61460AFSQRJRRQ1; IC_LM61460AFSQRJRRQ1; PARTREV D; JLC C2871455
U2: TPS62932; SOT-583-8

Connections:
+5V: C5.1, C6.1, C7.1, C11.1, C19.1, L1.2, R2.2, R5.2, U1.1 (BIAS); also elsewhere on the board
+8V: C17.1, C18.1, C20.1, L2.2, R6.2; also elsewhere on the board
+BATT: C1.1, C2.1, C3.1, C4.1, C8.1, C9.1, C13.1, C14.1, U1.7 (EN/SYNC), U1.8 (VIN1), U1.12 (VIN2), U2.2 (EN), U2.3 (VIN); also elsewhere on the board
CRBOOT: C12.2, U1.13 (RBOOT), U1.14 (CBOOT)
GND: C1.2, C2.2, C3.2, C4.2, C5.2, C6.2, C7.2, C8.2, C9.2, C10.1, C13.2, C14.2, C15.1, C18.2, C19.2, C20.2, R1.1, R4.2, R7.1, U1.3 (AGND), U1.9 (PGND1), U1.11 (PGND2), U2.4 (GND); also elsewhere on the board
unnamed: C11.2, R3.2
unnamed: R2.1, R3.1, R4.1, U1.4 (FB)
unnamed: R5.1, U1.5 (PGOOD)
unnamed: R1.2, U1.6 (RT)
unnamed: C12.1, L1.1, U1.10 (SW)
unnamed: C10.2, U1.2 (VCC)
unnamed: C16.1, U2.6 (BST)
unnamed: C17.2, R6.1, R7.2, U2.8 (FB)
unnamed: C15.2, U2.7 (SS)
unnamed: C16.2, L2.1, U2.5 (SW)

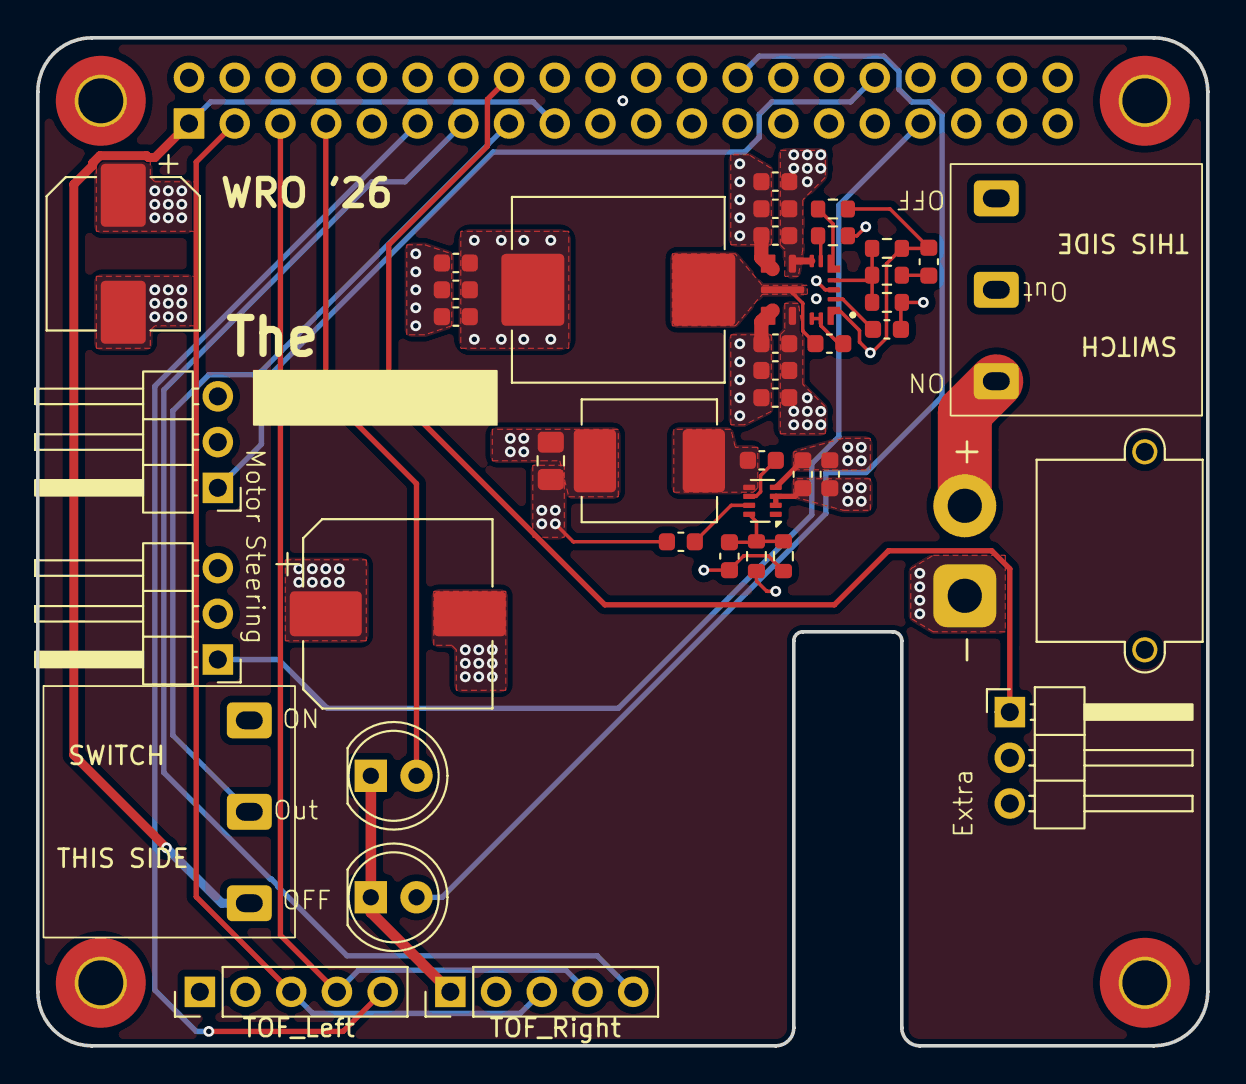
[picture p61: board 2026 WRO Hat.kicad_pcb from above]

Board: 4 copper layers, 65.0 x 56.0 mm, 46 parts (1 on the bottom side), 27 nets.

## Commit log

2026-07-21 Added PCB files and content in manual
    Almost completed section 2 in the engineering manual.
    [2026 WRO Hat.kicad_sch, PCB BOM.csv, WRO_Hat_V1.5_bom.csv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]
2026-07-21 Add README for PCB files and BOM information
2026-07-21 Enhance PCB readme with detailed file descriptions
    Expanded the readme to provide detailed descriptions of the PCB design files, including their purpose and usage instructions.
2026-07-22 Added PCB Schematic
2026-07-22 Update README
    Added details about the PCB V1.1 schematic and its pages.
2026-08-12 Added 3D files and updated Manual
    [2026 WRO Hat.kicad_pcb, 2026 WRO Hat.kicad_sch, Body Brace.step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]
2026-08-12 Revise README with team bios and hardware details
    Updated team member bios and hardware materials table formatting.
2026-08-12 Revise README for improved structure and details
    Updated README.md to enhance clarity and organization of content, including sections on folders, members, vehicle photos, hardware materials, and project timeline.
2026-08-12 Added and Updated Files
    Added logo.png and updated the manual.
    [PU ratios.csv]
